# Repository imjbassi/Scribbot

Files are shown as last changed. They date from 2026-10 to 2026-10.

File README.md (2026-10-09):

# Scribbot

A low-cost, mostly 3D-printed desktop robot arm that draws on a 3 × 3 inch sticky note.

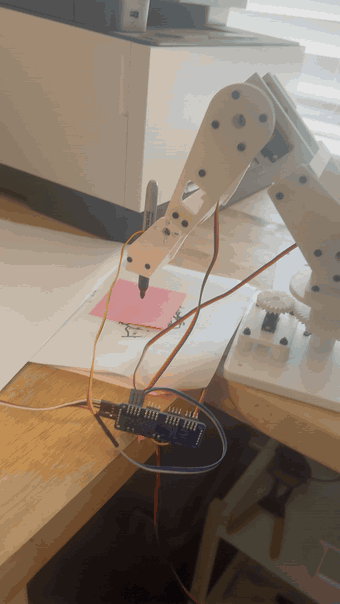
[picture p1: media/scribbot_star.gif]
Scribbot drawing a star on a sticky note


- **4 hobby servos:** MG90S base (through a 2:1 printed gear), MG996R shoulder, MG996R elbow, MG90S wrist
- **Electronics:** Arduino Nano + PCA9685 servo driver, 5 V supply
- **Pen:** a standard Sharpie in a gravity holder. It slides up a few millimeters when it touches the paper, so it presses with just its own weight.
- **Everything printable** is in OpenSCAD source plus ready-to-print STLs (PLA, 0.4 mm nozzle, 0.12 mm layers, no supports)
- **Planned:** a webcam stand and vision, so it can find the paper and draw what it sees

## Build stages

Each folder in [`design/`](design) has a `START_HERE.md` with print settings, hardware and step-by-step assembly, plus diagrams.

| # | Stage | Folder | Status |
|---:|---|---|---|
| 1 | Fit coupons: servo bodies, bearing pocket, slider clearance | [`phase-2`](design/phase-2) | Done |
| 2 | Servo mounting-hole templates | [`mounting-templates`](design/mounting-templates) | Done |
| 3 | Servo mount plates + bearing carrier | [`mechanical-fit-v1`](design/mechanical-fit-v1) | Done |
| 4 | Bearing turntable | [`compact-base-stage-1`](design/compact-base-stage-1) | Done |
| 5 | Base servo mount and gear mesh | [`compact-base-stage-2`](design/compact-base-stage-2), [`base-horn-fit`](design/base-horn-fit) | Done |
| 6 | First power-on: wiring + centering | [`base-servo-test`](design/base-servo-test) | Done |
| 7 | Base calibration + repeatability | [`base-calibration`](design/base-calibration) | Done |
| 8 | Shoulder + load test | [`shoulder-horn-fit`](design/shoulder-horn-fit), [`shoulder-stage`](design/shoulder-stage) | Done |
| 9 | Elbow | [`elbow-stage`](design/elbow-stage) | Done |
| 10 | Wrist + pen holder | [`pen-fit`](design/pen-fit), [`wrist-stage`](design/wrist-stage) | Done |
| 11 | Calibration and drawing software | [`calibration`](design/calibration), [`drawing`](design/drawing) | Done: draws squares, circles, stars and text |
| 12 | Camera stand + vision | | Planned |

[`rotating-base-v1`](design/rotating-base-v1) and [`compact-base-review`](design/compact-base-review) are earlier base designs kept for reference. Don't build them.

The running build log is [`design/CURRENT_BUILD_STATUS.md`](design/CURRENT_BUILD_STATUS.md).

## Geometry

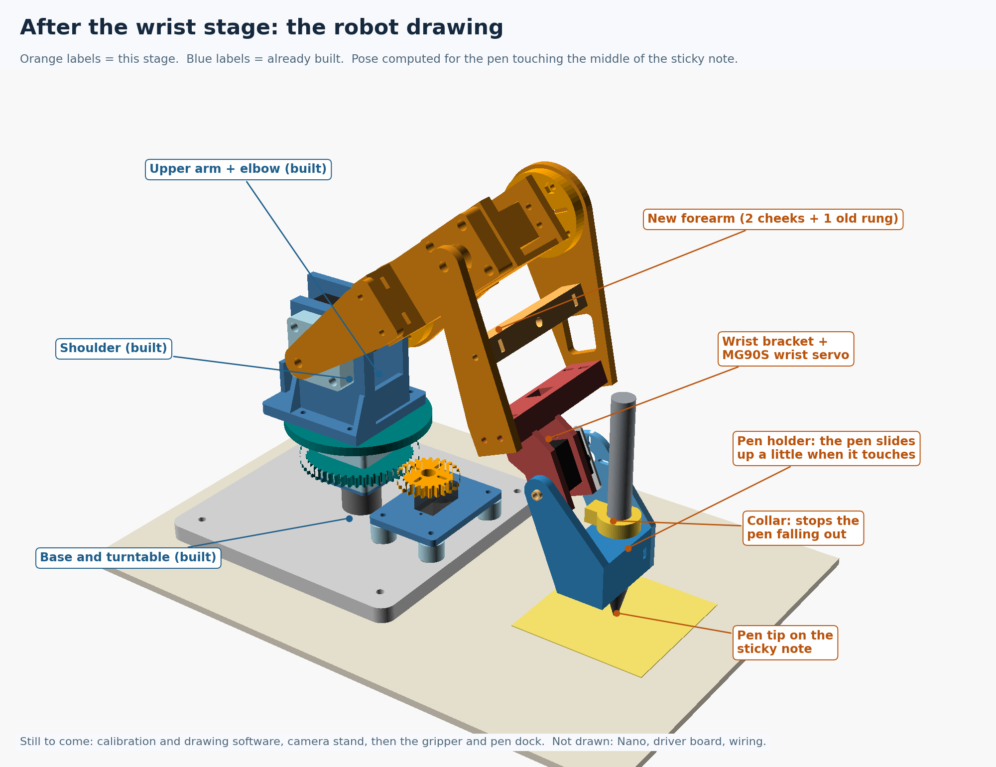
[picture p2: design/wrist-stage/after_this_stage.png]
Scribbot CAD model with its pen on the sticky note


| | |
|---|---|
| Upper arm, forearm | 120 mm each, joint to joint |
| Shoulder axis | 127 mm above the table (measured) |
| Pen | tip 67 mm below the wrist axis (measured), offset 25 mm forward |
| Drawing area | 60 × 60 mm patch on the sticky note, 135-197 mm out from the base |

## Wiring

| Nano | PCA9685 |
|---|---|
| 5V | VCC |
| GND | GND |
| A4 | SDA |
| A5 | SCL |

Servo power goes only into the PCA9685's green screw terminal, never through the Nano. Channels: 0 base, 1 shoulder, 2 elbow, 3 wrist.

## Test program

[`design/wrist-stage/arm_test/arm_test.ino`](design/wrist-stage/arm_test/arm_test.ino) drives all four joints over USB serial (115200 baud, no libraries needed). Commands start with the joint letter: `b` base, `s` shoulder, `e` elbow, `w` wrist. For example `s1300`, `e+`, `wo` (wrist off), or `o` for everything off. Outputs stay off at startup, and every move is slow and stepped.

## Calibration

The servo horns never land exactly on the design angles, so each joint gets an offset and a gain. They come from tape-measure heights of the shoulder, elbow, wrist and pen tip in three poses. In the last pose the wrist works as a level: the pen is set straight down and only the wrist pulse is read. The method and the numbers are in [`design/calibration/measurements.md`](design/calibration/measurements.md).

## Drawing

[`design/drawing/draw/draw.ino`](design/drawing/draw/draw.ino) does the inverse kinematics on the Nano and keeps the pen vertical. Lines are cut into 1 mm steps.

1. Put a sticky note with its center 166 mm (6 1/2 in) straight out from the turntable.
2. `h` hovers over the note. Lower the pen with `d` (1 mm) or `D` (5 mm) until it just touches the paper, then send `t` to save that height.
3. Draw:
   - `q` square
   - `c` circle
   - `s` star
   - `wHELLO` text: letters and numbers, up to 8 characters

`l` / `r` rotate the drawing 1°. `m` / `v` mirror or flip the text. `o` turns every joint off.

## License

[MIT](LICENSE): designs, STLs and code are free to use, modify and share, with the copyright notice kept.

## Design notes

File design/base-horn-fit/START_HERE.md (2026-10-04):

# One small gear: unpowered horn fit check

Print ONLY 01_motor_gear_fit.stl. This is the candidate base-drive pinion, not a release of the complete base. Your double-ended white horn is accepted as fitting your black MG90S shaft, based on your confirmation.

## Print

Use the Bambu A1 mini and the same PLA/profile used for the successful fit coupons: 0.4 mm nozzle, 0.12 mm layers, 0.2 mm first layer. Print flat, at 100% scale, with 4 walls, 5 top/bottom layers and 40% infill. No supports. Remove any brim from teeth and slots. This fit result will apply to this FDM process; resin needs its own fit validation.

## Check without screws or power

1. Leave the servo unplugged. Begin with the horn loose, off the servo.
2. Put the horn against the underside of the gear, with the socket that fits the servo pointing away from the gear. Center the horn's center hole in the gear's large center opening.
3. Align the horn arms with one pair of opposite radial slots. Look through the slots: at least one horn hole on EACH arm must be fully visible. Choose approximately equal distances from the center. You do not need to measure or mark anything.
4. Check whether the gear rests flat and centered against the horn arms. If the hub prevents it sitting flat, stop and report that; do not sand or force the horn.
5. Seat the horn back on the disconnected servo, gently, and hold the gear in place. Check whether the original center screw is accessible through the large gear opening and whether the gear clears the servo case. Do not turn the gear to force the servo shaft.

Reply: "holes line up, sits flat, clears case" or identify which check fails. A photo is useful if something does not line up.

Do not power this loose assembly. No attachment screws are selected yet: the slots are nominally 2.2 mm wide, but this does NOT prove the horn holes accept M2 screws. Screw diameter/length and underside clearance must be matched before fastening. Do not enlarge the horn holes or use glue.

## Design provenance

25 teeth, module 1.25, 6 mm thick; approximate envelope 33.7 x 33.7 x 6 mm. Central access opening 8 mm. Opposite attachment slot center positions span radii 7–11 mm. Geometry copied unchanged from compact-base-review. The photograph identifies the horn shape; no precise horn dimensions were inferred from perspective.

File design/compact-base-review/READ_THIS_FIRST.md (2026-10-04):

# Compact base revision — design review, NOT a print release

The earlier tall rotating-base-v1 package is superseded. Do not buy its 100 mm shaft, collars or M4 x 110 frame bolts for this revision. Keep the successful fit-test parts and bearings. This package is source CAD, reference renders and numerical design checks; it deliberately contains no printable STL release while the actual servo-horn interface remains unresolved.

## Settled layout for this revision

- Fixed 150 x 150 x 9 mm board-mounted base.
- One stationary M5 axle bolt, with two 625 bearings running on its smooth shank.
- Bearing INNER rings stay stationary; OUTER rings turn with the printed rotor, gear and top platform. This reverses the bearing arrangement of the withdrawn design.
- Bearing center spacing: 25 mm. Platform top: 67.4 mm above board.
- Target shoulder-axis height: approximately 115 mm, to be set by shoulder-carrier CAD. A central clearance well must accommodate the stationary bolt/nut stack up to approximately 86 mm above the board; no shoulder part may sweep through it.
- One MG90S beside the rotor, mounted in the previously accepted plate geometry.
- Printed 25-tooth motor gear drives a printed 50-tooth base gear, module 1.25 and 20-degree pressure angle. Nominal shaft spacing is 46.875 mm.
- The drive provides 2:1 torque multiplication before friction; 140 degrees of usable servo travel gives 70 degrees of base travel. Planned base range is -35 to +35 degrees, contingent on actual calibrated servo travel.
- Standard shoulder/elbow servos remain MG996R; optional wrist rotation remains in the mass budget. This base change does not resolve the outstanding shoulder thermal/load test.

## Complete load path

Arm/shoulder carrier -> rotating top platform -> bolted rotor and gear stack -> bearing outer rings -> balls -> stationary inner rings -> narrow washers and central support/spacer stack -> base board.

The MG90S drives through its supplied horn and the small gear. It supports the small gear and receives tooth reaction forces, but not the arm's weight. The pinion is not separately bearing-supported; the hobby servo output still sees gear-mesh radial force. This tradeoff must be checked at low acceleration, rather than claiming the servo shaft is entirely load-free.

## Motor connection: designed concept, one remaining physical check

The small gear bolts to the SUPPLIED horn; no printed spline is used. Candidate gear attachment slots accept M2-sized fasteners at radii 7–11 mm in four directions. The central 8 mm access hole allows the original horn screw to be reached. At least two compatible horn attachment locations are required, preferably on opposite arms. Fasteners must clear the servo case below and the large gear beside it.

The reference render assumes a double-ended 26 mm long, 2 mm thick horn, with attachment locations at +/-9 mm. These are placeholders, NOT measurements of the user's hardware. The photographed MG996R horn assortment does not establish the MG90S horn dimensions.

Update: IMG_9221.png shows a double-ended white horn with multiple holes per arm. The user confirmed this horn seats snugly on the black MG90S shaft without forcing. Shaft compatibility is accepted from that physical check. Exact hole diameters, horn thickness and fastener clearance remain unmeasured. The candidate motor gear is now released separately in ../base-horn-fit for an UNPOWERED alignment check only. Its slots must align with two opposite horn holes while centered. Do not force or drill the horn to match.

Gear-height alignment is adjustable by changing the four printed motor-post heights and using thin shims. The nominal 10 mm posts and 6.5 mm body-to-shaft offset in CAD are layout references. The base slots permit translation to align the gear axes and set mesh clearance. The motor gear and base gear must overlap axially without rubbing, and the original horn screw must be accessible before any powered test.

## Why this is preferable to the withdrawn base

It removes the separate precision shaft, two collars, tall two-deck frame and long M4 bolts. It places the arm much closer to the original height budget and makes the motor accessible from the side. The reduction improves base torque and halves the base angle change corresponding to a given servo angle change.

The tradeoff is printed gear backlash and limited yaw. Nominal tooth thinning produces 0.12 mm total pitch-circle backlash, equivalent to approximately 0.22 degrees at the base, or 0.77 mm at 200 mm radius. Real printed clearances, servo backlash, flex and wear can add more. This is a design calculation, not a measured accuracy specification. Avoid heavy grease on PLA; lubrication selection is not part of this release.

## Reach checks completed

With 120 mm links and an ideal vertical 95 mm tool offset, the checker sampled the 60 x 60 mm drawing patch (X=135..195, Y=-30..30 mm) at tip heights 2, 12 and 25 mm. It also checked provisional dock tip targets at X=145, Y=-75 mm, Z=10/25/40 mm. This replaces the old provisional dock location.

At each of six assumed shoulder heights from 100 to 125 mm, all 510 sampled targets had an IK solution within the chosen candidate joint limits. The dock yaw is approximately -27.35 degrees, within the planned +/-35-degree base sector. At the target 115 mm shoulder height, sampled joint ranges were approximately:

| Joint | Geometric angle range |
|---|---|
| Base yaw | -27.35 to +12.53 degrees |
| Shoulder | 29.15 to 57.87 degrees |
| Elbow | -111.49 to -68.73 degrees |
| Wrist pitch | -56.77 to -26.98 degrees |

These are geometric angles, not raw servo commands. Zero offsets and direction signs remain to be calibrated. The check does not prove full continuous-path coverage, physical servo travel, gripper/dock access, full-pen clearance, or self-collision avoidance. Complete shoulder, wrist and dock meshes are still needed for those checks. Do not use these numbers directly as servo targets.

The 2D involute gear profiles were checked in 561 sampled poses across the planned base range with zero polygon overlap at nominal spacing. Calculated nominal contact ratio is about 1.68. This is a tooth-profile interference check, not a torque, wear or printed-mesh test.

## Prospective parts list — do not purchase yet

### Already available or previously fitted

- 1 MG90S for base drive, with original horn and horn-center screw.
- 2 of the purchased 625-2RS bearings.
- Accepted MG90S plate geometry, rotated 90 degrees for this layout; the existing plate can be reused.
- One tested bearing cap can be reused; two caps total are needed. The old single-bearing carrier is a useful fit reference but does not become the new rotating rotor block.

### Proposed new hardware

| Part | Qty | Required check |
|---|---:|---|
| M5 x 80 partially threaded socket-head bolt | 1 | Smooth shank must cover both bearing journals; minimum approximately 55 mm from underside of head. Threads must reach upper nuts. Bearing fit must not visibly rock. |
| M5 hex nuts, approximately 4 mm thick | 2 | Lock together without overcompressing printed spacers or preloading bearings |
| Narrow M5 washers, 5.3 ID x 9 OD x 1 mm thick | 5 | Must contact inner races only; actual thickness affects axial stack |
| M3 x 45 machine screws | 4 | Through rotating platform + caps + rotor/gear stack |
| M3 nuts | 8 | Four rotor bolts and four motor-plate bolts |
| Thin M3 washers | 16 | Eight for rotor stack, eight for motor plate |
| M3 x 30 socket-head screws | 4 | Motor plate/post/base mounting; exact length after horn-height adjustment |
| M2 x 10 machine screws, M2 nuts, thin M2 washers | 2, 2, 4 | Existing proposed servo-tab fastening; use only if actual tabs accept it |
| Horn-to-gear fasteners | At least 2 | Diameter and length pending actual horn; not yet orderable |
| Approximately 4 x 16 wood screws and washers | 4 | Base to an 18 mm board; check actual engagement |

An undersized general-purpose bolt shank can introduce tilt even when its nominal diameter is M5. Do not assume the bolt is a precision shaft. Verify its two bearing fits before committing to loaded operation. If there is visible rocking or thread contact, this axle choice must be revised. The inner-ring spacers are printed to maximize printable content; compression/creep under clamping is another physical validation item. Jam nuts prevent loosening but do not justify overtightening.

### Proposed print list

Base x1; stationary pedestal x1; lower rotor block x1; upper rotor block x1; large gear x1; small gear x1; rotating platform x1; bearing caps x2 total; inner-ring spacer x1; top spacer x1; motor plate x1 total; motor posts x4. Gear and rotor blocks are separate so the gears can print flat without large unsupported overhangs and can be replaced individually.

## Assembly sequence after interface release

1. Check the actual bolt's smooth journal fit in both bearings and its thread reach. Fit the stationary axle through the base from below, with its head recessed.
2. Stack the stationary pedestal and first narrow washer on the axle. Lower bearing bottom is nominally Z=30.2 mm.
3. Build the rotating shell loosely from lower cap, lower rotor block, large gear and upper rotor block around the axle. The two bearings sit at opposite ends of the 16.3 mm bore; their separation is set by the inner-ring spacer stack, not by the servo.
4. Between the bearings fit a narrow washer, the 18 mm inner spacer, and a second narrow washer. Fit the upper bearing, then the top cap and platform. Bolt the rotating stack with four M3 x 45 screws and washers/nuts. Ensure the bearing outer rings are captured without seal rubbing.
5. Above the upper inner race, fit a narrow washer, 10 mm top spacer, another washer and the two M5 nuts. Adjust to hold the inner-ring stack while allowing free rotor movement. Nominal total outer-race axial freedom is 0.4 mm; printed and washer tolerances may require spacer adjustment. Do not squeeze away a tight spot by tightening harder.
6. Attach the actual supplied horn to the disconnected MG90S using its original screw. Attach the small gear with the matched fasteners once that interface is released. Install the motor plate, posts and servo; align gear height and mesh without binding.
7. Disconnect/disengage the motor gear for the first free-turn test. Then mesh the gears and check tooth engagement gently within the calibrated range; do not force the servo through a hard stop by turning the platform.
8. Only after mechanical fit, safe pulse calibration and the future joint-limit procedure should unloaded powered tests begin. No firmware is supplied in this review package.

## Superseding physical-fit update

The user confirmed the printed motor gear sits flush, opposite holes align, it clears the MG90S case, and the center screw remains accessible. These checks pass. Horn-to-gear fastening is still unresolved; the user has only supplied servo screws. The next limited release is ../compact-base-stage-1: a passive turntable prototype, motor detached. Its instructions supersede the earlier request to repeat the horn fit check. The full powered base remains unreleased.

## Previous next-action note (superseded)

Use the separate base-horn-fit instructions for the small gear alignment check. Do not print the full base or buy the prospective hardware yet. The existing fitted components remain valid. The next release should contain a matched motor connection, final hardware schedule and one assembly guide, rather than another disconnected test structure.

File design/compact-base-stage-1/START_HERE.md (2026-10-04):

# Use the consolidated build guide

Open [BUILD_GUIDE.html](BUILD_GUIDE.html). It is the current guide and includes the fully threaded axle limitation, hardware inventory, numbered diagram and expanded assembly steps. No STL geometry changed.

The earlier instructions below are retained as a design reference; follow the consolidated guide when they differ.

---

# Next build: passive compact turntable

This is the bearing-supported rotating base, assembled WITHOUT the motor gear engaged. It is an engineering prototype for physical fit and hand-turn testing, not a validated complete robot. The old tall base remains superseded.

## Confirmed and pending

You confirmed the white horn fits the black MG90S, the small gear sits flush, opposite holes align, the gear clears the case, and the center screw is accessible. Keep that printed gear. Those checks do not establish attachment screw size or loaded performance. You have only the supplied servo screws. Do not force them into the horn or substitute a long screw for the original center screw. Horn-to-gear fastening remains pending; the motor stays detached in this stage.

## Print list

Print flat as exported, 100% scale, PLA, 0.4 mm nozzle, your tested 0.12 mm layer / 0.2 mm first-layer profile. Use 4 walls, 5 top/bottom layers and 40% infill; use 100% infill for the pedestal and both inner-ring spacers. No supports. Inspect bridges over underside base recesses; remove loose strands before fitting hardware. Do not transfer the validated FDM clearances directly to resin.

| File | Total quantity | Notes |
|---|---:|---|
| 01_base.stl | 1 | 150 x 150 mm; new compact base |
| 02_fixed_pedestal.stl | 1 | Narrow end points upward |
| 03_lower_rotor.stl | 1 | 9 mm tall |
| 04_large_gear.stl | 1 | 50 teeth |
| 05_upper_rotor.stl | 1 | 15.4 mm tall |
| 06_bearing_cap.stl | 2 total | Reuse your accepted plain cap; print only one more if you have one |
| 07_top_platform.stl | 1 | 80 mm diameter |
| 08_inner_spacer_18mm.stl | 1 | Between inner bearing races |
| 09_top_spacer_10mm.stl | 1 | Above upper inner race |

Ten pieces total, or nine new pieces if reusing one cap. Reuse the small gear and MG90S mounting plate later. The old single-bearing carrier is NOT one of the new rotor blocks. Print one file at a time or arrange separate plates; do not stack the STLs on the slicer bed.

## Hardware required for this stage

This is a dimensional specification, not a verified supplier listing. Check any hardware you already own before ordering.

- Two 625-2RS bearings, 5 x 16 x 5 mm, from your existing supply.
- One M5 x 80 partially threaded socket-head bolt. Its smooth shank must extend at least 55 mm from under the head, with usable threads at 66.7–74.7 mm from under the head. A fully threaded bolt is unsuitable. Head must fit a 9.6 mm diameter x 5.5 mm-deep recess. Both bearings must slide onto the smooth shank without visible rocking; a nominal M5 label alone does not prove the fit.
- Two ordinary M5 hex nuts, approximately 4 mm thick each, used as jam nuts.
- Five narrow washers: approximately 5.3 mm ID, 9 mm OD, 1 mm thick. They must bear on the bearing INNER metal ring without touching the rubber seal. Check the actual bearing contact; dimensions alone do not guarantee seal clearance.
- Four M3 x 45 machine screws, four M3 nuts and eight thin M3 washers (approximately 0.5 mm thick). These clamp the rotating shell, not the fixed axle.

Do not buy the withdrawn design's 100 mm shaft, collars or long frame bolts. No motor fasteners or board screws are required for the initial bench fit. The base must later be secured before powered or loaded use.

## Assembly: two stacks share one axle

Use numbered_connection_guide.png alongside this sequence; its part numbers match the STL filenames. The inner stack stays still. The outer shell rotates around it. All heights are nominal; washer and print thickness affect the fit.

1. With the axle loose, check both bearings on its SMOOTH shank. Stop if the fit rocks visibly, binds, or puts a bearing on threads.
2. Insert the M5 bolt upward through the base from underneath. Seat its head in the recess. Place the pedestal over the axle, narrow tip upward, then one narrow washer.
3. Lower a bearing cap and the lower rotor over the pedestal tip. Insert the lower bearing into the rotor from above, sliding its inner ring onto the axle until it rests on the narrow washer. The bearing must be supported through its inner ring; do not press through its seal.
4. Add a narrow washer, the 18 mm spacer and another narrow washer onto the axle. Add the large gear and upper rotor around that stack. Align all four corner holes through the rotating parts.
5. Slide the upper bearing into the upper rotor from above until its inner ring reaches the washer. Add the second bearing cap and top platform. Insert four M3 x 45 screws through the corner-hole stack with washers and nuts. Tighten evenly only until seated; stop if tightening introduces binding or distorts the prints.
6. Above the upper bearing INNER ring, add a narrow washer, the 10 mm spacer and the fifth narrow washer. These pass through the cap/platform center opening. Add the two M5 nuts. The lower nut holds the stationary inner stack; the upper nut locks against it. Hold the lower nut while tightening the upper so you do not change the stack compression.
7. The design leaves approximately 0.4 mm total outer-ring axial clearance. Check for rubbing and excessive play. Do not eliminate binding by overtightening. If the washer stack differs or the assembly binds, report it so spacer length can be adjusted.

## Pass/fail before adding the motor

With the motor gear detached and no arm attached, hold the base and turn the platform by hand through one full turn. Bearing seals may add gentle, consistent drag.

PASS: smooth movement without a tight spot, no seal/cap scraping, no visible rocking of the platform, axle remains fixed, and the printed stack stays clamped. Repeat after locking the M5 nuts.

FAIL: catching, grinding, obvious wobble, bearing threads contact, or movement becomes tight after locking nuts. Stop and identify which symptom occurs. Do not add the motor or power it to overcome resistance.

Report: "turntable turns smoothly, no wobble" or the symptom. This test establishes unloaded fit only; loaded deflection, backlash, thermal behavior, fasteners and powered travel remain later checks.

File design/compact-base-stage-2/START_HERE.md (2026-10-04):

# Stage 2: fit the MG90S beside the turntable

## Current status

You assembled the turntable with a fully threaded M5 axle and reported smooth turning and secured side bolts. Earlier wobble was reported; its cause and loaded behavior are not established. At your request, axle replacement is deferred for an UNLOADED prototype. Keep the arm off; inspect for renewed rocking, binding or wear before moving on to loaded work. This supersedes the earlier instruction to stop all fitting work pending axle replacement.

This stage positions the servo and checks gear height. It does not release powered operation. The horn-to-gear screws remain unspecified.

## Print only these two files

- posts_set_of_4.stl: print ONE copy of this file. It already contains all four 10 mm motor posts.
- shoes_set_of_4.stl: print ONE copy of this file. It already contains all four thin backing plates.

Use your tested PLA process, 0.4 mm nozzle, 0.12 mm layers, 0.2 mm first layer, 100% scale, 4 walls and 100% infill; flat as exported, no supports. Do not print four copies of either file. The post height is provisional until the real installed horn height is checked.

Reuse your accepted MG90S mounting plate and small gear. Do not reprint the turntable. The existing plate is 64 x 44 mm; rotate it so its long direction runs front-to-back along the base's motor slots. Its raised label faces up.

## Hardware from your M3 kit

Four M3 x 30 BUTTON-head screws, eight M3 flat washers, four M3 nuts. Do not use M4 screws or split lock washers. The button heads are the low rounded heads in your first kit.

The backing plates bridge the wide slots underneath the base. Each is 10.4 x 18 x 1 mm, with a 3.4 mm hole. They belong inside the elongated underside recess, not on top of the base. Their narrow edge leaves limited adjustment; do not force them beyond the recess. This is a prototype printed support for the small motor mount, not a tested structural washer replacement for other joints.

## Install each of the four mount bolts

See motor_mount_guide.png. Start beneath the base:

M3 screw head -> M3 flat washer -> thin printed backing plate -> slotted base -> 10 mm post -> existing MG90S plate -> M3 flat washer -> M3 nut.

1. Lift/support the base to reach its underside; do not dismantle the central turntable.
2. Put a washer on each M3 x 30 button-head screw. Pass it through a backing plate, then UP through a motor slot from below. The backing plate's 18 mm direction follows the long recess.
3. Put one 10 mm post over each screw on TOP of the base.
4. Lower the existing servo plate onto all four posts. Add washers and nuts above it. Leave the nuts loose enough for gentle adjustment.
5. Check underneath. Each backing plate must lie flat in its recess and bridge the slot. Screw heads must not make the base rock on the table. If they protrude or a backing plate bends, stop and report that; do not crush it by tightening.

## Place the servo and check gear height

6. With its horn removed, gently feed the MG90S lead and body through the plate's rectangular opening from ABOVE. Mounting tabs rest on the plate. Do not trap the cable between the plate, posts or base. If the cable plug will not pass, route it before lowering the plate.
7. The servo shaft faces UP. Start with the output shaft approximately aligned with the middle of the large gear in the front-to-back direction; the adjustment slots compensate for the actual servo shaft offset. Keep the small gear out of mesh for now.
8. Servo-tab fastening is not resolved by the M3 kit: the plate has 2.2 mm mounting holes. Do not force M3 screws into them. You may hold the servo seated by hand for this static alignment check. This is not a secure operating mount.
9. Seat the already-tested white horn on the shaft without forcing or twisting it. Hold your small gear on top in its confirmed flush orientation. It is not secured yet; keep a hand on it.
10. Look from the side. The two gears are each 6 mm thick. Their top and bottom faces should be at approximately the same heights, with most of their tooth height overlapping. If the small gear is high or low, do not tilt the servo plate: all four posts must change height equally. The 10 mm posts are a starting point, not a measured final height.
11. Move the plate gently toward the large gear until teeth can enter the gaps. If tooth tips meet, move apart and rotate the LARGE platform slightly, then bring them together. Do not force the small gear or back-drive the servo. The plate should remain level; neither gear nor horn should rub the servo case or platform.
12. Take a SIDE-ON photo showing both gears and the servo plate. Keep the small gear loose and disengage it after the check. Do not rotate the whole assembly as a driven system until the gear is fastened and servo travel is calibrated.

## Report these three things

- Does the servo plate sit level, with the base still flat on the table?
- Is the small gear level with the large gear, higher, or lower?
- Does the cable have clearance without being pinched?

A side-on photo can answer most of this. Include the supplied servo screws beside the assembly if handy; that helps distinguish the original center screw from the mounting screws without assuming their sizes.

## Before powered use (not completed in this stage)

Select and verify servo-tab fasteners and two opposed horn-to-gear fasteners, resolve actual gear height and mesh clearance, secure the base, and calibrate the servo with the gears disengaged. The original center screw attaches the horn to the servo; it does NOT secure the printed gear to the horn. Do not glue the gear or substitute a longer center screw.

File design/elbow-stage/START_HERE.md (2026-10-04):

# Stage 6: elbow joint

The elbow is a copy of the shoulder joint, carried on a short new upper arm. Your 120 mm test arm is not wasted: it moves out to the elbow and becomes the forearm.

Pictures in this folder:

- `after_this_stage.png`: what the robot looks like when this stage is done
- `construction_diagram.png`: exploded view, numbered in build order
- `screw_map.png`: every screw, lettered, with what it passes through

## Print

All PLA, your 0.12 mm profile, 100% scale, flat as exported, no supports.

| File | Qty | Settings |
|---|---:|---|
| 09_elbow_bracket.stl | 1 | 3 walls, 20% infill. Prints standing up, 85 mm tall, thick end plate on the bed. |
| 10_upper_cheek_A_hub_side.stl | 1 | 4 walls, 40% |
| 11_upper_cheek_B_bearing_side.stl | 1 | 4 walls, 40% |
| 01_hub_PRINT_1_MORE.stl | 1 | 4 walls, 40% |
| 03_bearing_housing_PRINT_1_MORE.stl | 1 | 4 walls, 40% |
| 04_bearing_cap_PRINT_1_MORE.stl | 1 | 4 walls |
| 08_axle_spacers_PRINT_1_MORE.stl | 1 | 100% infill |

## Hardware (new for this stage)

- The second MG996R, its double-arm horn, 2 horn screws and its center screw
- 1 × 625 bearing
- 1 × M5 bolt, washer and nut, the same kind you used at the shoulder
- M3 × 16: 8, M3 × 20: 4, M3 × 12: 4, M3 nuts: 12, M3 washers: 8

## Wiring and program

- Elbow servo plugs into **channel 2** on the driver board (next to the shoulder on channel 1), brown wire toward the board edge.
- Upload `arm_test/arm_test.ino`. It drives all three joints. Every command starts with the joint letter: `b` base, `s` shoulder, `e` elbow. Examples: `e1500`, `s+`, `eo` (elbow off), `o` (everything off).

## Build order (numbers match construction_diagram.png)

**Take the test arm off the shoulder first**
1. Type `o` and unplug the adapter. Support the arm.
2. Undo the M5 nut and washer on the bearing side. Take out the 3 rung screws on cheek B and pull cheek B off. Leave the spacers on the bolt.
3. Undo the 4 screws holding cheek A to the shoulder hub. The test arm (cheek A with its 3 rungs) comes off as one piece. Leave the hub on the servo.

**Upper arm onto the shoulder**
4. Upper cheek A onto the shoulder hub with the same 4 screws, pointing **straight forward**, where the test arm pointed.
5. Drop 4 M3 nuts into the slots at the two ends of the bracket's thick end plate. Hold the bracket between the cheeks with its two walls pointing away from the shoulder. The **thin wall with the window goes on the hub side**. Two M3 × 16 through cheek A into the bracket.
6. Upper cheek B over the shoulder bolt, two M3 × 16 into the bracket, then the M5 washer and nut back on.

**Elbow joint (same as the shoulder)**
7. M5 bolt through the bearing and new housing, cap on, 4 × M3 × 20 into the bracket's back wall. Bolt head inside the big hole. Leave the screws slightly loose.
8. Plug the second servo into channel 2. Power on, type `e1500`, then `eo`, and unplug. The servo is now centered.
9. Slide the servo into the bracket's window from the hub side. Its shaft must line up with the big hole in the back wall, so the **shaft end points away from the shoulder**. Bolt the tabs with 4 × M3 × 16, washers and nuts.
10. Press 4 M3 nuts into the new hub's hex pockets. Screw the horn to the hub with 2 horn screws. Press it onto the shaft and put the center screw in.
11. Test arm onto the new hub with 4 × M3 × 12, pointing **straight down** when the upper arm is level (a right angle to the upper arm, as close as the horn's teeth allow). Raise the upper arm by hand first so the forearm has room.
12. Spacers on the elbow bolt, cheek B over the bolt, its 3 rung screws back in, then the M5 washer and nut.
13. Swing the forearm gently by hand to line up the bearing, then tighten the 4 housing screws.

## First power-on

Keep the base clamped. Hold the forearm lightly in your hand.

1. Type `s1500`. The upper arm goes level.
2. Raise the upper arm: on the shoulder, **lower numbers go up**. Type `s1400`, `s1300`, `s1200`, `s1100`, `s1000`, pausing at each, until it is about halfway to vertical. This gives the forearm room. The program stops the shoulder at 1550, just below level.
3. Type `e1500`. The forearm should hang at a right angle to the upper arm.
4. Type `e1400`, then `e1600`, then `e1500`. It should swing smoothly both ways.

**Stop** (type `o` with the arm supported) if anything binds, buzzes loudly or heads for the table.

## Report back

- Which elbow number swings the forearm **forward and up** (away from the base): `e1400` or `e1600`?
- Does it all move smoothly? A photo of the arm helps.

## Known limits

- The test arm is heavier than the final forearm will be. It is fine for this stage; a lighter forearm comes with the wrist.
- With the upper arm level and the elbow at a right angle, the forearm reaches the table. Raise the shoulder before bending the elbow down.
- Collision checks in CAD: forearm against upper arm clear from 20° past straight to folded 140°; arm against the shoulder mount clear from level to 120° up. The base, table and cables are not in that check.

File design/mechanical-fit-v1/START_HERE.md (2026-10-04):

# First mechanical interfaces — fit release V1

This release converts the accepted mounting templates into removable screw-mounted servo plates and a common base interface. It also tests a captured 625 bearing. It is NOT the complete robot, a finished shoulder/elbow joint, or a load-test fixture. No servo should be powered in this assembly yet.

Editable OpenSCAD source: set `part` to `assembly_micro`, `assembly_standard`, or `exploded_standard` to inspect the pedestal arrangement. Gray servo boxes are approximate envelope references only, and omit ears, horns, screws and wires. Never export these assembly previews as printable parts. Export the individually named part options instead. STEP files are not included in this OpenSCAD fit release.

## Print first

Print one each of `01_mg90s_mount_plate.stl`, `02_mg996r_mount_plate.stl`, `03_625_bearing_carrier.stl`, and `04_625_bearing_cap.stl`. Each has one part. Print flat, labeled face up where present, at 100% scale with your confirmed PLA/0.4 mm nozzle/0.12 mm layer profile and 0.20 mm first layer. Use four walls and at least five top/bottom layers; no supports. Print carrier pocket upward. Clear loose strings without enlarging fit surfaces.

Do not print extra shoulder/elbow copies yet. These plates establish interfaces for those later modules; their carrier structures and horn couplings are still pending.

## What to test

### Servo plates

Feed the cable through the body opening, then insert the servo from the labeled side. Tabs rest on the 4 mm thick plate. Check that every intended screw location aligns while the body sits naturally. There must be no need to bend tabs or squeeze the body. Reference openings are 23.4 x 12.8 mm for MG90S and 41.3 x 20.3 mm for MG996R.

MG90S uses the selected 27 mm spacing and 2.2 mm holes intended for M2 machine screws. MG996R uses 49 x 10 mm spacing and 3.4 mm holes intended for M3 machine screws. Actual servo slot width and supplied screws have not been verified. Try any available correctly sized screw gently; do not drill the servo or force an oversized screw. A smaller screw with appropriate washers can be evaluated if the slot will not accept the proposed size. The supplied coarse servo mounting screws are not assumed to match these machine-screw holes.

The four outer M3 holes on either plate have identical 52 x 32 mm center spacing. They attach the plate to a pedestal independently of the servo tab screws. Use washers on servo tabs where they fit without touching the body; tighten only enough to retain the servo without deforming its plastic tabs. Report interference instead of forcing it.

### Bearing carrier and cap

Insert ONE 625-2RS bearing into the 16.3 mm pocket from above. It should seat on the narrow outer support rim; nominal bearing top is 0.2 mm below the housing top. Set the cap over it, aligning four holes. The 14.6 mm central openings retain the bearing near its outer edge while leaving the shaft and inner race clear. Confirm the printed rims do not rub either rubber seal: actual bearing ring geometry varies.

With the cap held in place by fingers, turn the inner ring gently. Compare freedom of rotation with the loose bearing. If it binds or the seal rubs, stop and report it. Then, if hardware is available, fit four M3 x 16 machine screws, eight thin M3 washers and four M3 nuts. Tighten evenly and lightly. Check again. The bearing must not escape and should have only small axial clearance, not intentional preload. No axle or servo load is applied in this test.

The later major joints use TWO bearings each; this test only validates one retained bearing interface. It does not prove bending capacity, shaft alignment or a complete load path. Smooth metal journals and inner-race spacers will be specified with the complete joint; do not use bolt threads as final bearing journals.

## Optional base assembly after plate fit succeeds

`05_base_plate.stl` is 150 x 150 x 7 mm plus its label and fits the A1 mini bed. Print label upward; the small 7 mm underside counterbores require short bridging, not supports. `06_mg90s_spacers_4x.stl` contains four 20 mm high spacers; `07_mg996r_spacers_4x.stl` contains four 35 mm high spacers. Use only the matching spacer set for whichever servo plate is installed. They provide an open-sided, removable pedestal, not a closed housing. Verify clearance under actual servo cases, case screws, connectors and wire bends before tightening.

Stack, from bottom up: M3 screw head + washer, base plate, spacer, servo plate, washer + nut. Four M3 x 35 screws suit the nominal micro stack, or four M3 x 50 suit the standard stack. Check protrusion with actual nuts/washers. Under-base nuts for the servo tab screws remain separately accessible. The base access window and open sides allow cable routing and access.

Both servo plates fit the same outer bolt pattern; this makes the mounting platform swappable. Their OUTPUT SHAFT positions are not guaranteed to coincide. A later bearing support and horn coupling must align to each actual servo shaft; this release does not claim a drop-in drive-axis upgrade.

Board holes are 4.5 mm diameter on 124 x 124 mm centers. Four approximately 4 x 16 mm wood screws and washers suit an 18 mm board with this 7 mm base, subject to actual screw/washer thickness. Four underside pockets, 7 mm diameter and 3.6 mm deep, recess the module's M3 socket heads and thin washers. Check that these sit flush or below the bottom surface before anchoring the base. Use washers that fit the recess; report any protrusion rather than bending the base flat. Remove the base from the board to access the recessed heads when changing the module.

## Hardware for one initial fit of each plate and one bearing pod

No purchases are needed just to check that the servo bodies and bearing seat correctly. For screw-fastened checks, the following is a provisional allocation, dependent on actual servo slots accepting the screw diameters:

| Item | Quantity | Purpose |
|---|---:|---|
| M2 x 10 machine screw | 2 | MG90S tab attachment |
| M2 nut | 2 | MG90S tab attachment |
| M2 thin washer | 4 | MG90S attachment, clearance permitting |
| M3 x 12 machine screw | 4 | MG996R tab attachment |
| M3 x 16 machine screw | 4 | Bearing cap |
| M3 nut | 8 | Standard servo and bearing cap |
| M3 thin washer | 16 | Standard servo and bearing cap |
| Owned 625-2RS bearing | 1 | Retention test |

Optional base pedestal: four M3 x 35 OR four M3 x 50 screws, four M3 nuts and eight thin washers. The micro mounting interface introduces M2 hardware because these tabs should not be assumed to accept M3. Final arm quantities remain pending assembly CAD.

## Report back

1. MG90S: sits flat, both holes align, screw size tried (if any).
2. MG996R: sits flat, all four holes align, screw size tried (if any).
3. Bearing: seats fully, cap sits flat, inner ring still turns freely.
4. Any rubbing, interference or loose fit; a photo is useful if unclear.

Remaining mechanical work: output-horn attachment, shaft-axis position, bearing-support carriers, link geometry, complete assembly clearances, gravity/load verification and wrist module packaging. Earlier inferred tab heights are provisional; this release uses open space and through-fasteners to avoid tightly fitting unverified tab thicknesses.

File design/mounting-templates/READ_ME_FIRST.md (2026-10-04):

# Servo mounting-pattern fit templates

Print one copy of each STL. These are thin fit gauges, not operational brackets.

## Settings

Use your tested A1 mini setup: 0.4 mm nozzle, Generic PLA profile, 0.12 mm layers and 0.20 mm first layer. Print flat, labels up, 100% scale, no supports or raft. All islands must remain at their original scale if rearranged. MG90S layout is 82 x 83 mm; MG996R layout is 128 x 168 mm, within a 180 mm square bed. If a brim exceeds the slicer's allowed area, omit it or rearrange the individual pieces. Do not print both complete layouts together unless rearranged to fit.

Each STL contains multiple separate labeled plates: five MG90S options and nine MG996R options. Keep labels readable; remove loose strings without enlarging the holes.

## How to test

1. Keep the servo unplugged and remove any output horn that obstructs handling. Do not remove its case screws.
2. Feed the cable connector through the large rectangular opening first. Lower the servo body into that opening from the labeled side, so its mounting tabs rest on the plate.
3. Gently center the body in the opening. Its clearance is intentional; do not push it to one end to make only one hole align.
4. Hold the plate and servo together and inspect from UNDERNEATH, using a light. Compare each small printed hole with the rounded center of the servo mounting slot above it. Look for symmetric alignment at BOTH ends; on MG996R check all FOUR holes simultaneously.
5. Choose the label whose holes are most centered together. These small holes are visual references, not finished screw clearance holes. No new screws, pins or tools are required. Do not force screws through them.
6. Send the winning label for each servo. If adjacent options look equally good, send both labels and an underside photo of the best seated fit. If none fits, report that instead of forcing it.

The template is symmetric; servo direction does not matter. Raised labels sit outside the nominal servo footprint. If a particular servo's tab reaches a raised label and cannot sit flat, report that interference.

## Options

| Label | MG90S A, mm |
|---|---:|
| M1 | 27.0 |
| M2 | 27.5 |
| M3 | 28.0 |
| M4 | 28.5 |
| M5 | 29.0 |

| Label | MG996R A, mm | MG996R B, mm |
|---|---:|---:|
| S1 | 49 | 9 |
| S2 | 49 | 10 |
| S3 | 49 | 11 |
| S4 | 50 | 9 |
| S5 | 50 | 10 |
| S6 | 50 | 11 |
| S7 | 51 | 9 |
| S8 | 51 | 10 |
| S9 | 51 | 11 |

A is the lengthwise spacing between corresponding hole centers on opposite ends. B is the spacing between the two holes on ONE MG996R mounting tab.

These are candidate dimensions, not measurements inferred as certain from the photos. Existing confirmed body openings are 23.4 x 12.8 mm for MG90S and 41.3 x 20.3 mm for MG996R. This test checks body-to-hole-pattern alignment; it does not establish output shaft position, horn fastening geometry, tab thickness or structural strength. The next bracket fit test will retain adjustability where needed.

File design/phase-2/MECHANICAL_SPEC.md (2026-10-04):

# Vision Draw Arm — phase 2 preliminary design

Status: engineering proposal and printable fit tests; not a validated arm assembly.

## Accepted configuration

Use two positional 180-degree MG996R servos (shoulder and elbow), and four owned MG90S servos (base yaw, wrist pitch, optional removable tool roll, gripper). The roll axis is along the pen axis when drawing. It rotates the gripper and cartridge for dock alignment, and remains fixed during drawing. It must not be implemented as a sideways wrist yaw axis: that would change the constrained inverse kinematics. Leave enough wire loop for limited roll, never continuous rotation.

Links are 120 mm center-to-center. Shoulder height is nominally 100 mm above the board. Target wrist-to-tip distance is 95 mm with the roll module; it must be measured on the assembled tool and entered into calibration. Base plate remains 150 mm square. Maximum straight-link reach is 240 mm, not the recommended drawing radius.

Use a single approximately 76.2 mm square sticky note, not a stack. Initial drawing region is 60 mm square. Measure the actual note before changing holder parameters. Place its center nominally at robot (165,0) mm, edges parallel to robot X/Y, giving drawing bounds X=135..195, Y=-30..30 mm. Maximum radial drawing distance is approximately 197.3 mm. Put the adhesive edge against a registration edge. The holder bed is 2 mm thick; calibrate paper Z on its actual surface. Recess all mounting screws or keep them outside the motion envelope.

Provisional dock location is (130,-90) mm, radius 158.1 mm. This is a layout target only: full pen length, upper barrel sweep, jaw opening and all approach heights must pass collision checks before fixing the dock. Provide slotted dock mounting in later CAD.

## Wrist module load budget

Original endpoint gripper/cartridge/pen budget: 60 g. Add 13.4 g roll servo and 15 g combined roll bracket, bearing/bush and coupling allowance: 28.4 g increase. Tool endpoint budget becomes 88.4 g. Keep total wrist-to-tip length at or below 95 mm if feasible. Weigh the completed tool; an overweight tool triggers recalculation.

Horizontal gravity estimate, mass in kg and radius in cm:

Shoulder = 0.045*6 + 0.075*12 + 0.040*18 + 0.025*24 + 0.0884*24 = 4.6116 kgf cm.

Elbow = 0.040*6 + 0.025*12 + 0.0884*12 = 1.6008 kgf cm.

At 2x allowance these become 9.2232 and 3.2016 kgf cm. The shoulder is almost at the published 9.4 kgf cm stall figure at 4.8 V. This is insufficient evidence of a thermally reliable shoulder. Previous confidence in the five-servo configuration does not carry over unchanged to the roll-equipped version.

Retain the roll module as requested, but require a shoulder load test before full-arm printing. The standard bracket should allow a later servo replacement. If the test fails, first remove roll and retest; then choose between a measured counterbalance solution and a stronger shoulder servo with verified dimensions and ratings. Do not assume a generic “20 kg” label solves backlash or thermal duty. Do not increase the supply voltage without verifying every attached servo.

The calculation assumes the distal assembly is centered below the wrist when drawing. During handling its horizontal center-of-mass offset can increase shoulder torque by up to approximately 0.0884*9.5=0.84 kgf cm in an unfavorable orientation. Such poses are excluded from the initial loaded motion plan. Pen drag and acceleration add load; the 2x number is an engineering allowance, not a continuous torque rating.

## Mechanical interfaces to implement after measurement

- Base, shoulder and elbow use six total 625-2RS bearings (5x16x5 mm). Smooth metal journals carry bearing inner races; clamped printed carriers carry outer races. Hardware geometry must be resolved in assembly before ordering final pivot bolt lengths.
- Use supplied servo horns, never printed splines. The horn transmits torque; separately supported pivots carry structural loads. Provide accessible center screws and removable couplings.
- Link ends use removable end fittings and M3 captive-nut interfaces. Nominal tool-module interface: four M3 clearance holes on a 24 mm square, centered on the tool axis. This is a reserved envelope, not a released fabrication drawing.
- Tool roll uses a coaxial removable cartridge and limited angular travel. Keep the complete pen, including barrel above the grip, inside collision models. A servo/body interference check is required before releasing wrist CAD.
- The compliant pen cartridge has 6 mm stroke, keyed slider, positive retaining flange and adjustable spring seat. Spring force target is approximately 0.1–0.4 N, plus moving weight and friction. Calibrate force with a scale before drawing.
- Use a gripper with synchronized opposing racks. Grip the cartridge neck below its flange. The dock supports the cartridge without loading the pen tip and leaves both jaws clear.

## Exact measurements needed

Measure one representative MG90S, then check the others for differences. Repeat for the actual purchased shoulder/elbow servos. Record in MEASUREMENTS.csv, in millimeters. A digital caliper is helpful.

1. Body length and width below the mounting ears, excluding wires.
2. Body depth below mounting ears and total height to top of output shaft.
3. Overall mounting-ear span and ear thickness.
4. Mounting-hole center spacing in both directions and hole diameter.
5. Output-axis location from two perpendicular body faces.
6. Supplied horn diameter/length, thickness, fastening-hole pattern and installed offset from the body.
7. Center screw specification from supplied hardware; do not guess thread size.
8. Wire exit location and bend-clearance envelope.
9. Actual positional travel after gentle bench calibration; do not command hard stops.
10. Pen diameter, total length, grip-to-tip distance, mass; sticky-note width/thickness; webcam dimensions/mass; resin name/type and its recommended post-cure process.

No exact servo ear spacing or spline geometry has been assumed in the fit coupons. They test BODY clearance only. Do not force a servo through a coupon or use the coupon as a structural bracket.

## First prints and how to judge them

Print MG90S coupon, bearing coupon and slide coupon first in the FDM material intended for final parts. Use 0.2 mm layers and the same wall settings as the later bracket. Each separate coupon island is intentionally disconnected in the STL. Raised labels identify opening allowances. Print flat, without support, and remove elephant-foot edges before evaluating.

MG90S and MG996R coupons provide total added body width/length of 0.4, 0.6 and 0.8 mm (half that clearance per side). Select the smallest opening that accepts the body without force. The MG996R coupon should wait until the actual servos arrive. A body's rounded corners and taper may require additional changes.

Bearing coupons have through-bores of 16.0/16.1/16.2/16.3 mm. Select a sliding/snug hand fit; retention will come from caps, not heavy interference. Slide channels provide 0.2/0.3/0.4 mm lateral clearance per side. Select a channel that moves freely after cleaning, then test again under representative side load. This open channel only measures lateral fit; it is not a finished anti-rotation linear guide.

The note holder is an initial flat backing and registration fixture, sized for a single nominal 76.2 mm note. Its two low edges locate the note, leaving opposite edges accessible. It has four 4.5 mm mounting holes outside the paper. Verify the note stays flat; adhesive variability may require a small removable edge tape outside the drawing patch. This first holder is parameter-adjustable by reprinting, not mechanically adjustable. A later slotted guide version can accommodate multiple sizes without reprinting.

Resin is optional for dimension coupons, gripper pinion/racks, cartridge inserts and fixtures. Use a suitable tough/engineering resin after checking its datasheet; ordinary brittle resin is not the default for structural links, flexures or screw-loaded servo brackets. Evaluate fit after full prescribed post-cure. Resin shrinkage means FDM-selected clearances do not transfer automatically. Use the printer/material manufacturer's handling and processing instructions.

## Bench gates before completing the arm

These are proposed project acceptance criteria, not manufacturer limits or measured performance.

### Shoulder load test

1. Mount the servo and supplied horn on a rigid temporary fixture. Support the test lever so radial load is not carried solely by the servo spline. Provide a catch under the lever and accessible power disconnect.
2. Confirm unloaded movement around the intended working pose, calibrated pulse range and stable supply voltage.
3. For the roll-equipped gravity budget, an approximately 235 g load at 200 mm gives 4.7 kgf cm. Subtract the lever's own moment from the added load. Begin at 25% load, then 50%, 75%, 100%, supporting it while changing weights.
4. At each step hold for 30 seconds, checking for sag, buzzing and supply collapse. At full load extend to 2 minutes, then 10 minutes only if stable. Do not deliberately stall the servo.
5. Conservative project stop: case surface reaches 45 C, rises more than 20 C above ambient, motion becomes unstable, or supply falls below the servo's verified minimum. Use a thermometer; touch is not a measurement.
6. Pass: no stop condition, less than 1 degree additional sag from the settled starting position, and no continued rapid temperature rise at ten minutes. Passing supports a prototype only; repeat with actual duty cycle and complete arm later.

### Base repeatability

1. With links supported and pen lifted, attach a lightweight 200 mm pointer or use the final pen over a reference grid.
2. Command the same central target 20 times from clockwise approach and 20 times from counterclockwise approach at low speed.
3. Measure endpoint position after settling each time. Pass for initial 60 mm symbols: total spread no more than 2 mm and mean approach-direction separation no more than 2 mm. If failed, inspect horn fastening, bearing fit and cable torque; do not claim software interpolation removes backlash.

### Dock pickup

1. First perform ten open-gripper approaches above the dock, then lower incrementally after checking clearances.
2. Grip the cartridge, lift 20 mm, hold five seconds, replace, open and withdraw. Run slowly with an accessible disconnect.
3. Pass: 20 consecutive complete cycles without dropping, binding, scraping the tip, or shifting the cartridge grip height by more than 0.5 mm. Failure requires dock/gripper changes before adding automatic vision.

### Compliance and drawing

1. With the tool held vertical, measure force against a scale at several displacements through the usable stroke. Confirm return without sticking and no coil bind.
2. Start with approximately 2 mm compression and at least 3 mm remaining stroke. Verify paper force is suitable for the chosen pen.
3. Draw repeated 40 mm squares and circles inside the 60 mm region using known coordinates. Record closure error, repeatability and paper damage before enabling vision.

## Software consequences and next stage

Set paper size to measured dimensions, independent of draw-region size. Use a 60 mm drawing square centered on the note. Four ArUco markers go on the surrounding rigid board, not inside the small note. Marker-to-note position is fixed by the holder only after calibration.

Constrained IK remains base yaw plus planar shoulder/elbow plus compensating wrist pitch. Tool roll is an independent fixed angle during drawing, provided the roll axis and pen axis are coaxial. Recalibrate tool length for each installed module. Use measured joint travel and collision validation, not assumed 0–180 degree mechanical travel.

Next release: measured servo envelopes, complete supported joint geometry and horn adapters, base/shoulder/link CAD, assembly-specific hardware schedule and collision-checked motion envelope. Do not order all final screw lengths or print the full arm from this preliminary package. STEP and complete assembly files are not included in this fit-test release.

## Reference specifications

- https://towerpro.com.tw/product/mg996r/ — nominal MG996R body, mass and stall torque. Manufacturer distinguishes positional travel variants.
- https://towerpro.com.tw/product/mg90s-3/ — nominal MG90S body and mass. Verify the actual owned units and supply rating.
- https://learn.adafruit.com/16-channel-pwm-servo-driver/hooking-it-up — separate logic and servo power wiring.

These sources were inspected during phase 1. Their figures are reference inputs, not measurements of the user's hardware.

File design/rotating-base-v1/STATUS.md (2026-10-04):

> SUPERSEDED — DO NOT PRINT OR BUY FROM THIS PACKAGE.
> The compact-base-review revision replaces this tall prototype. See outputs/CURRENT_BUILD_STATUS.md. Existing fit-test results remain valid.
# Stage status

Completed digitally: seven printable part types, parameterized OpenSCAD source, stationary frame and rotating platform assembly preview, exploded view, hardware schedule, assembly order, mesh validation and selected analytical clearance checks.

Physical basis: the user accepted the prior servo mounting plates and the one-bearing carrier/cap fit. The carrier/cap geometry is reused unchanged.

Not yet validated: shaft fit, platform clamp, frame stiffness, two-bearing alignment, bearing axial retention under actual arm load, or thermal/torque performance. No loaded or powered test has been performed.

Pending input: identify the supplied MG90S horn (double-ended, cross-shaped or single-ended) and verify its usable attachment-hole geometry before releasing the motor coupling. A photo of the actual horn will be useful for the attachment layout; no motor adapter is included in this release.

Design departure: the prototype platform sits approximately 142 mm above the board. Shoulder-axis height and the original 60 mm drawing patch must be revalidated with the eventual shoulder carrier. This is a mechanical base prototype, not a finalized full-arm workspace layout.

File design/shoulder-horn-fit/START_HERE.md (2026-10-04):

# Shoulder horn fit check (unpowered)

Print ONLY `01_shoulder_hub.stl`: one copy, flat as exported, PLA, 0.12 mm layers, 4 walls, 40% infill, no supports.

This is the real shoulder drive hub, not a throwaway coupon. It bolts to the MG996R's double-arm horn. Later, the upper arm bolts to it with four M3 screws into the hex nut pockets on its underside.

## Check (servo unplugged, no screws yet)

1. Hold the horn under the hub, with the **hex pockets facing the horn**. Center the horn's middle screw in the hub's big center hole.
2. Turn the horn until its two arms line up under one pair of **opposite slots**. On each arm, at least one horn hole should be fully visible through the slot, at about the same distance from the center on both sides.
3. The hub should sit **flat** on the horn, not rocking.
4. Put the horn back on the MG996R shaft (gently, don't twist the shaft) and hold the hub on top.
   - Can you reach the horn's center screw through the hub's center hole?
   - Does the hub clear the servo case all the way around?

## Report

"holes line up, sits flat, clears case", or which check fails. A photo helps if something is off.

Also tell me whether the MG996R came with any other horns (round disc, cross, single arm), and what small screws came with it.

## Later (not yet)

- Horn to hub: two of the horn's small supplied screws, down through the slots. The counterbores leave 2.5 mm of plastic under the screw heads, so short screws reach.
- Upper arm to hub: four M3 screws into M3 nuts pressed into the hex pockets.

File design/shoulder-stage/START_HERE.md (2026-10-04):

# Stage 5: shoulder mount + load test

Build the MG996R shoulder on the turntable with a 120 mm **test arm**, then check that the servo can hold the weight of a full arm without sagging or overheating. This is the shoulder load test from the original spec. Nothing in the real arm gets printed until this passes.

- `everything_so_far.png`: the whole robot so far, assembled and labeled
- `construction_diagram.png`: exploded view, every part numbered in build order (use this one)
- `servo_orientation.png`: which way round the MG996R goes (its shaft is off-center)
- `screw_map.png`: every screw, lettered A-G, with what it passes through and how many
- `assembly_preview.png`: what it looks like built
- `assembly_stack_diagram.png`: schematic top view of the stack

## Print

All PLA, your 0.12 mm profile, 100% scale, flat as exported, no supports.

| File | Qty | Settings |
|---|---:|---|
| 02_shoulder_carrier.stl | 1 | 5 walls, 40% infill. Prints standing up (base plate on the bed). |
| 03_bearing_housing.stl | 1 | 4 walls, 40% |
| 04_bearing_cap.stl | 1 | 4 walls |
| 05_lever_cheek_A_hub_side.stl | 1 | 4 walls, 40% |
| 06_lever_cheek_B_bearing_side.stl | 1 | 4 walls, 40% |
| 07_lever_rung_PRINT_3.stl | **3** | 4 walls, 40% |
| 08_axle_spacers.stl | 1 | 100% infill (6 small rings) |

You already have `01_shoulder_hub` from the horn fit check.

## Hardware

| Item | Qty | Used for |
|---|---:|---|
| M3 × 16 screw + nut + washer | 4 | carrier to platform (same holes as the pointer) |
| M3 × 16 screw + nut + washer | 4 | servo tabs to carrier |
| M3 × 20 screw + washer | 4 | cap + housing into the carrier's back wall (screws thread into the plastic, no nuts) |
| M3 × 12 screw + nut | 4 | cheek A to hub (nuts press into the hub's hex pockets) |
| M3 × 16 screw + nut | 6 | rungs to cheeks (nuts drop into the rung slots) |
| **M5 × 30 bolt** + M5 nut + M5 washer | 1 | shoulder stub axle on the bearing side |
| 625 bearing | 1 | from your spares |
| Horn screws (came with the MG996R) | 2 | horn to hub |

**M5 × 30:** if you only have the long M5 × 80, it works for this test; the extra length just sticks out sideways.

For the load test you also need an empty water bottle, string or a zip tie, a measuring cup (1 mL of water = 1 g), and something to act as a catch under the arm (a box or a stack of books).

## Before you start

- **Secure the base to the table** with clamps or lots of strong tape. The test arm plus weight can tip the robot over.
- Remove the calibration pointer from the platform.
- Plug the MG996R into **channel 1** on the driver board (the next column over from the base servo), brown wire to the board edge.

## Build order (the order matters)

1. **Carrier onto the platform.** Use the same 4 holes and screws as the pointer. Either direction works; the easy way is screws up from below with the nuts on top, like you did for the pointer. See `carrier_on_your_photo.png`. Do this before anything else; the servo covers two of the screws.
   **Then aim it at the sticky note.** The carrier sits a quarter turn from where the calibration pointer sat, so the arm would point sideways. With the power off, loosen the 4 motor-plate nuts and slide the plate back until the gears separate. Don't turn the small gear. Turn the platform by hand until the carrier's short end (where the arm will stick out) faces the sticky note. Slide the plate back in to re-mesh and tighten the nuts. See `everything_so_far.png`.
2. **Bearing side.** Press the bearing into the housing pocket. Put one 1 mm spacer on the M5 bolt, then push the bolt through the bearing from the housing's flat side (the side without the pocket), so the head ends up on the flat side. Put the cap over the pocket. Hold the housing against the back wall's outer face (the bolt head goes into the big hole, threads pointing out), and thread in the 4 × M3 × 20 with washers. **Leave them slightly loose** so the housing can still slide a little.
3. **Center the servo.** Upload `shoulder_test/shoulder_test.ino`, plug in the adapter, and type `c`. The MG996R goes to its center. Then type `o` and unplug the adapter.
4. **Servo into the carrier.** The shaft is near one end of the servo body, not in the middle; see `servo_orientation.png`. Slide the body through the window from the hub side (the side away from the back wall), shaft pointing away from the back wall. Turn it so the **shaft end faces the SHORT end of the base plate** and the shaft lines up with the big round hole in the back wall. Check from the hub side, looking square on: the shaft (or the hub's center screw) should sit directly above the round hole in the middle of the base plate, not off to one side. The cable comes out at the shaft end on this servo. Bolt the tabs with 4 × M3 × 16, nuts on the inside.
5. **Hub onto the servo.** Press 4 M3 nuts into the hub's hex pockets first. Screw the horn to the hub (2 horn screws through opposite slots). Press the horn onto the shaft so the hub's small top dot points **up and forward**, about 45°. The arm should point about 45° up when the servo is centered. Put the center screw in through the hub.
6. **Build the test arm.** Drop an M3 nut into each rung-end slot. Screw all 3 rungs to cheek A (M3 × 16).
7. **Arm onto the hub.** Hold cheek A against the hub and screw it on with 4 × M3 × 12 into the hub nuts. The arm should point forward and up.
8. **Cheek B.** Slide spacers onto the M5 bolt until they fill the gap between the bearing and cheek B (start with the 8 mm + 1 mm). Fit cheek B over the bolt and screw it to the 3 rungs. Add the M5 washer and nut outside and tighten.
9. **Line up the bearing.** Swing the arm to horizontal by hand (gently). Now tighten the 4 housing screws. Cheek B is narrow so you can reach them. The housing shifts itself into line with the servo shaft as you tighten.

**Check:** power on, `c`, then `1300` and `1700`. The arm swings smoothly with no binding or creaking. If it binds, loosen the housing screws, run `c` again, and re-tighten.

## Load test

**Setup.** Put the catch (a box) under the arm tip, about 1 cm below horizontal, so the arm lands on it if power drops. Stand a tape measure upright next to the end rung to watch for sag.

1. Power on, type `c`. Use `+` / `-` to make the arm **exactly horizontal** (a phone level app on the arm helps). Write down that pulse.
2. Tie the empty bottle to the hole in the **end rung** with string or a zip tie.
3. For each step: add water, return to the horizontal pulse, type `t` to start the timer, and watch the arm tip on the tape measure.

| Step | Bottle + water | Hold |
|---|---:|---|
| 25% | 55 g | 30 s |
| 50% | 150 g | 30 s |
| 75% | 250 g | 30 s |
| 100% | 345 g | 2 min, then 10 min if everything is fine |

(A typical empty bottle weighs about 10 g, so 345 g is about 335 mL of water.)

**Stop immediately** (lower the arm onto the catch with `-`/`+`, then `o`) if:
- the servo gets **hot**. Warm is okay; too hot to keep a finger on means stop. An infrared thermometer is better if you have one: stop at 45 °C.
- it **buzzes loudly**, jitters, or the arm creeps down.
- the arm tip sags more than **about 2 mm** from where it started (about 1°).
- the voltage at the green terminal drops below **4.8 V** (measure it during the 100% hold).

**Pass:** 100% held for 10 minutes: no stop condition, sag under about 2 mm, servo no more than warm.

## Report back

- The horizontal pulse
- For each step: did it hold? Any sag (tape reading start and end)?
- How warm the servo got at 100% after 2 min and after 10 min
- Voltage at the terminal during the 100% hold

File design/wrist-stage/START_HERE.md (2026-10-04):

# Stage 7: wrist and pen holder

A small MG90S at the end of a new forearm tilts a pen holder, so the pen can stay straight up and down whatever the arm is doing. The Sharpie slides freely in the holder: when the robot lowers it onto the paper, the pen rides up a few millimeters and presses on the paper with just its own weight. A collar stops it falling out.

Pictures in this folder:

- `after_this_stage.png`: the whole robot with the pen on the sticky note
- `construction_diagram.png`: exploded view, numbered in build order
- `screw_map.png`: every screw, lettered, with what it passes through

## Print

All PLA, your 0.12 mm profile, 100% scale, flat as exported, no supports.

| File | Qty | Settings |
|---|---:|---|
| 12_forearm_cheek_A_hub_side.stl | 1 | 4 walls, 40% |
| 13_forearm_cheek_B_bearing_side.stl | 1 | 4 walls, 40% |
| 14_wrist_bracket.stl | 1 | 3 walls, 20%. Stands on its thick end plate, 53 mm tall. |
| 15_pen_holder_arm_A.stl | 1 | 4 walls, 40% |
| 16_pen_holder_body.stl | 1 | 3 walls, 15%. The pen hole runs sideways and has a pointed top on purpose, so it prints without supports. |
| 17_pen_collar.stl | 1 | 4 walls, 40% |
| 18_pivot_sleeve.stl | 1 | 100% infill (tiny tube) |

The test arm's cheeks and two of its rungs retire. Keep **one rung** (with its nuts): it goes into the new forearm.

## Hardware

- One MG90S from your box, with its bag (horn, horn screws, center screw, 2 tab screws)
- New: M3 × 16: 5, M3 × 12: 3, M3 nuts: 8, M3 washer: 1
- Reused: the 4 × M3 × 12 that held the test arm to the elbow hub, the rung's 2 screws, the elbow's M5 washer and nut
- 3 male-to-female jumper wires (your ELEGOO kit) to extend the MG90S cable, which is too short to reach the driver board

## Wiring and program

- Extend the MG90S cable with the 3 jumpers, matching colors, and plug it into **channel 3** (next to the elbow), brown toward the board edge.
- Upload `arm_test/arm_test.ino` from this folder. It drives four joints: `b` base, `s` shoulder, `e` elbow, `w` wrist. The wrist is limited to 1350-1650 until we know which way it turns. The elbow now stops at 1900 so the new forearm can't fold into the upper arm.

## Build order (numbers match construction_diagram.png)

**1. Take the test arm off the elbow**, the same way you took it off the shoulder: M5 nut off, cheek B's 3 rung screws out, cheek B off, then the 4 screws holding cheek A to the elbow hub. Keep one rung and all the screws.

**Steps 2-7 happen on the table, on the wrist bracket alone.**

2. Find the bracket's two walls: the **tab wall** has the rectangular window, the **back wall** has a small slot-shaped hole.
3. Plug the MG90S into channel 3, power on, type `w1500`, then `wo`, and unplug. It is now centered. Slide it into the window from the side away from the back wall. Shaft points **away from the back wall**, and the shaft end goes toward the **open end** of the bracket, away from the thick end plate. Two tab screws into the wall.
4. Horn onto the shaft. Pen-holder arm A goes on the horn: counterbored face outward, 2 horn screws through opposite slots. Turn the horn so arm A's wide end points **straight along the bracket, away from the end plate**. Then the center screw.
5. Drop an M3 nut into the slot-shaped pocket on the servo side of the back wall. Drop 2 M3 nuts into the slots on the long sides of the pen-holder body, near the top.
6. Push the pivot sleeve through the hole in the body's arm B, then hold the body so arm B sits outside the back wall and the sleeve goes into the slot.
7. M3 × 16 with the washer through the sleeve into the nut. **Leave it loose.** Bring the body up against arm A and screw them together with 2 × M3 × 12. Wiggle the holder up and down a few times, then tighten the pivot screw.

**Steps 8-10 put it on the arm.**

8. Rung onto forearm cheek A, in the hole near the round end (M3 × 16).
9. Drop 4 M3 nuts into the 4 slots at the ends of the bracket's thick end plate. Hold the bracket against cheek A with the **MG90S horn side facing cheek A**. Two M3 × 16 through cheek A into the end plate. Then cheek A onto the elbow hub with the 4 × M3 × 12, forearm pointing **straight down when the upper arm is level**, like the test arm was.
10. Spacers on the elbow bolt, cheek B over it, then 3 screws into cheek B: one into the rung, two into the end plate. Elbow M5 washer and nut back on.

**Steps 11-12: the pen.**

11. Nut into the collar's side slot, M3 × 12 started in it. Slide the collar onto the Sharpie (cap off), about halfway up.
12. Drop the pen tip-first down through the holder, from the side where the collar will rest. Slide the collar until about **1 inch of pen** sticks out of the bottom of the holder, and tighten the collar screw just snug.

**Check:** push the pen tip up gently with a finger. It should slide up and drop back by itself, without catching.

## First power-on

Base clamped. Support the forearm with your hand at first.

1. `s1500`, then raise the shoulder in steps: `s1400`, `s1300`, `s1200`, `s1100`.
2. `e1500`. The forearm hangs at a right angle to the upper arm.
3. `w1500`. The pen lines up with the forearm.
4. Try `w1450` and `w1550`. **Which one tilts the pen tip forward**, away from the base toward the sticky note?

Stop (`o`, arm supported) if anything rubs, buzzes loudly or heads for the table.

## Report back

- Which wrist number tilts the pen tip forward: `w1450` or `w1550`?
- Does the pen slide freely in the holder?
- Anything rubbing? A photo of the wrist helps.

Next comes calibration: teaching the software the exact angle each servo pulse gives, then the first drawn square.

## What was checked in CAD (not yet on the real robot)

- All 7 parts are single, watertight solids and fit the A1 mini bed.
- Pen holder vs the wrist bracket and servo: clear from -75 to +45 degrees of wrist turn.
- Pen (full 125 mm Sharpie) vs the forearm: clear from -75 to +15 degrees. Drawing needs -11 to -42.
- New forearm vs upper arm: clear from +20 down to -125 degrees of elbow; touches at -140, hence the 1900 limit.
- Drawing poses (pen on the paper and 25 mm above it, near and far edges of the sticky note): the arm clears the shoulder mount and the table.
- MG90S size, shaft position and horn height are estimates. The pivot slot gives the holder about 1.5 mm of adjustment to line up with the real shaft.

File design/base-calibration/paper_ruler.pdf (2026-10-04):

# Paper ruler for the base calibration

Print at "Actual size" / 100% (not "Fit to page"). Cut out one strip and tape it under the pen.

Check: the bar below should measure 85.6 mm, the same width as a credit card.

0 | 1 | 2 | 3 | 4 | 5 | 6 | 7 | 8 | 9 | 10 11 12 13 14 15 16 17

cm

0 | 1 | 2 | 3 | 4 | 5 | 6 | 7 | 8 | 9 | 10 11 12 13 14 15 16 17

cm

0 | 1 | 2 | 3 | 4 | 5 | 6 | 7 | 8 | 9 | 10 11 12 13 14 15 16 17

cm

Three copies in case one gets cut wrong. Numbers are centimeters; small ticks are millimeters.

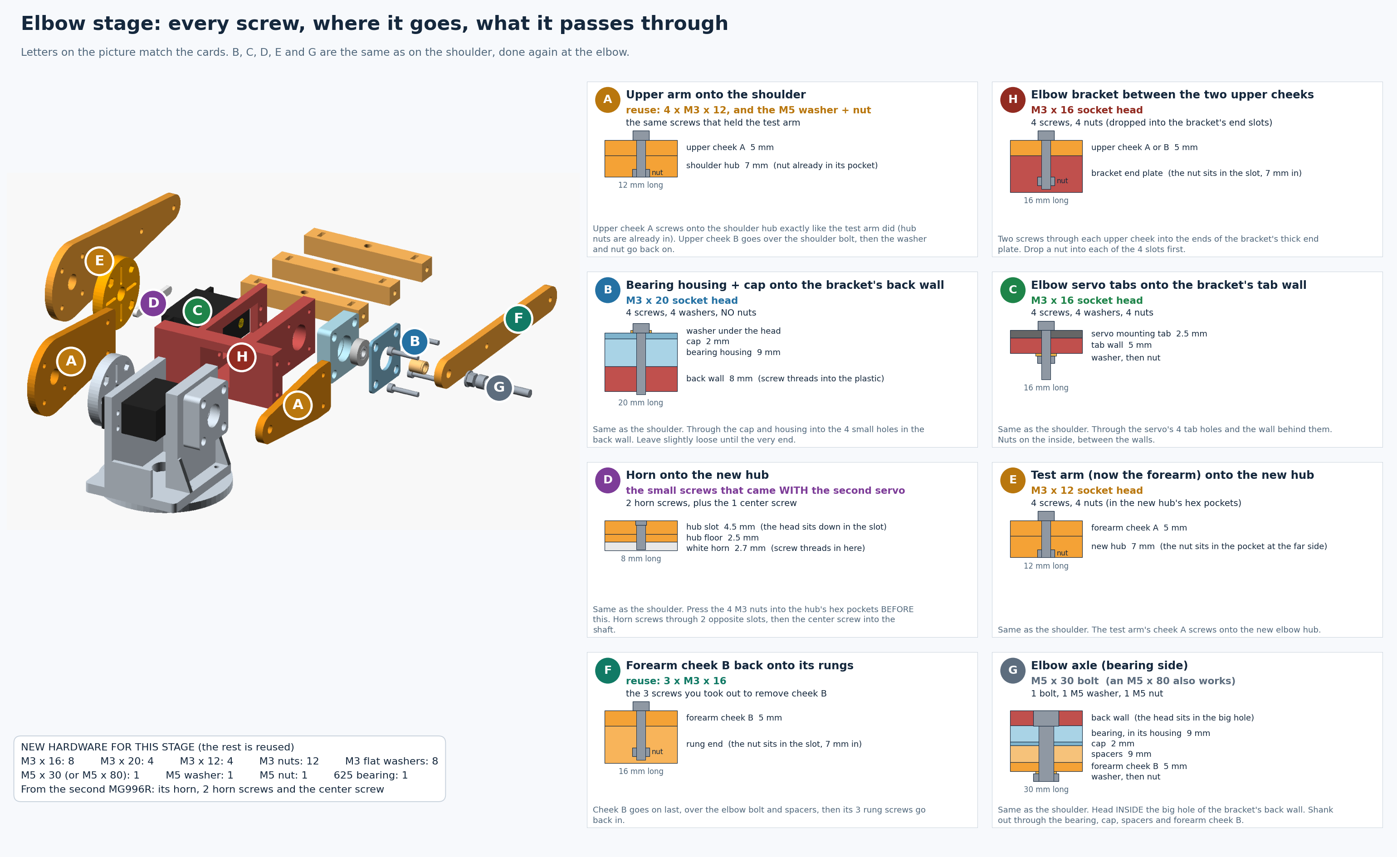
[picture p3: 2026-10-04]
design/elbow-stage/screw_map.png

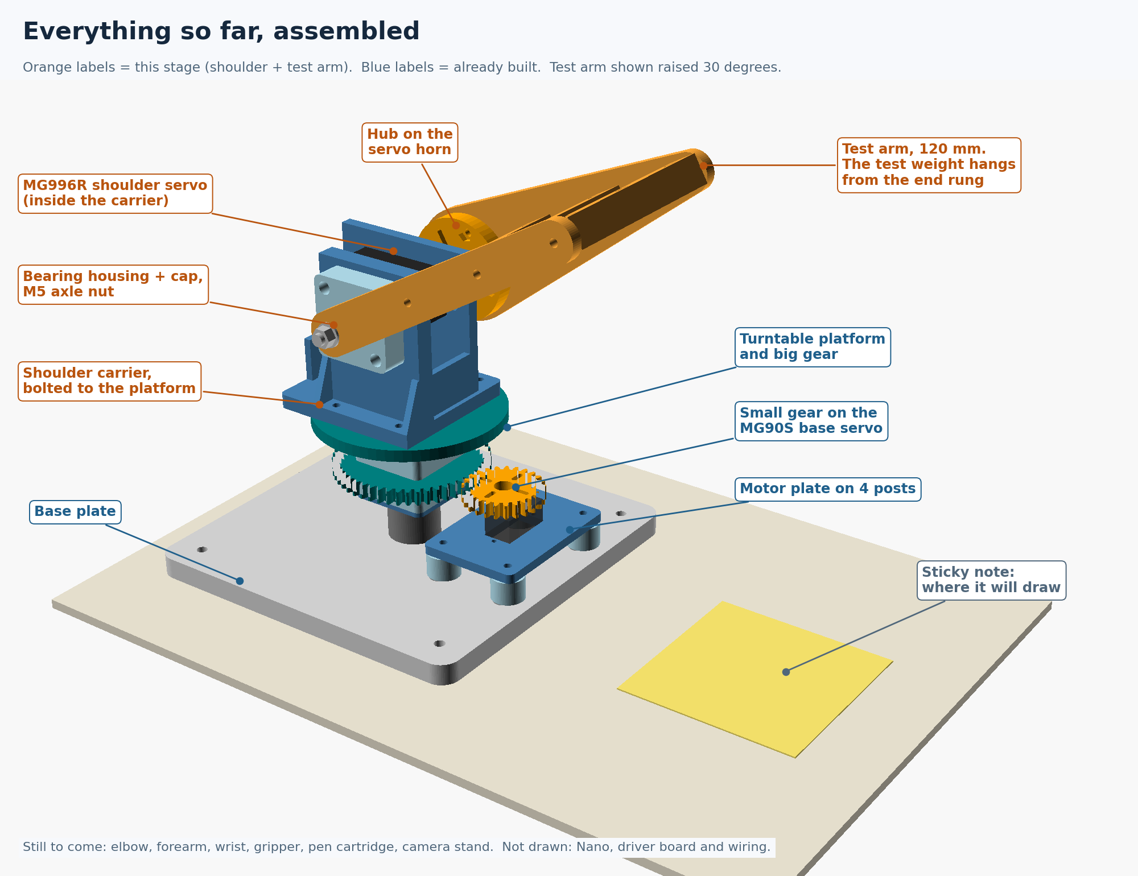
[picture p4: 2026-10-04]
design/shoulder-stage/everything_so_far.png

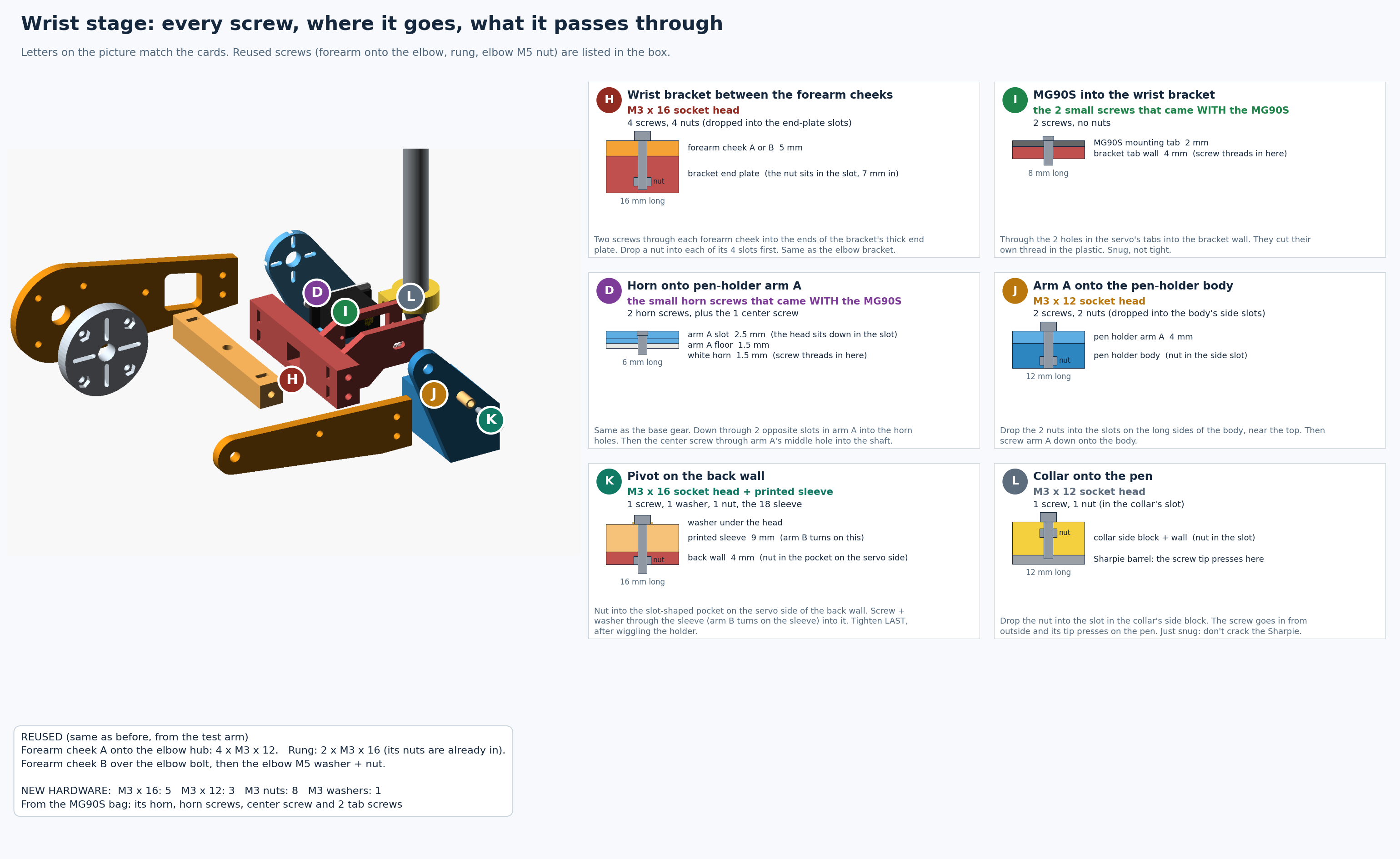
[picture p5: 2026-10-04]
design/wrist-stage/screw_map.png

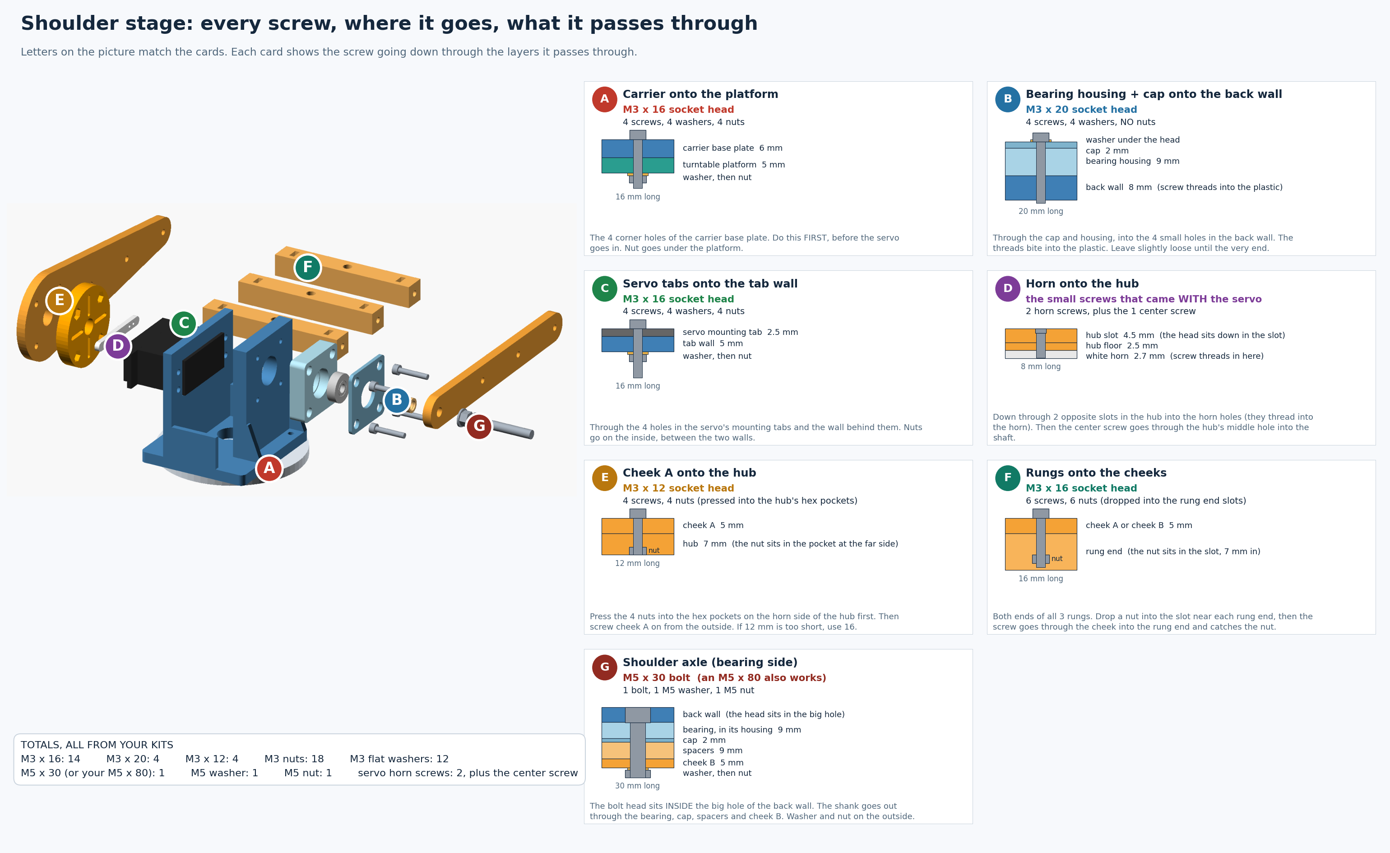
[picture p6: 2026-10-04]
design/shoulder-stage/screw_map.png

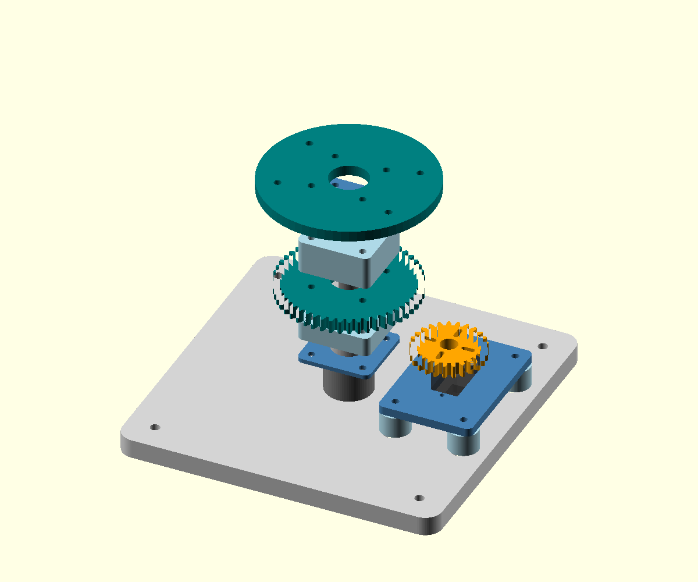
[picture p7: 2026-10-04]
design/compact-base-stage-1/exploded_preview.png

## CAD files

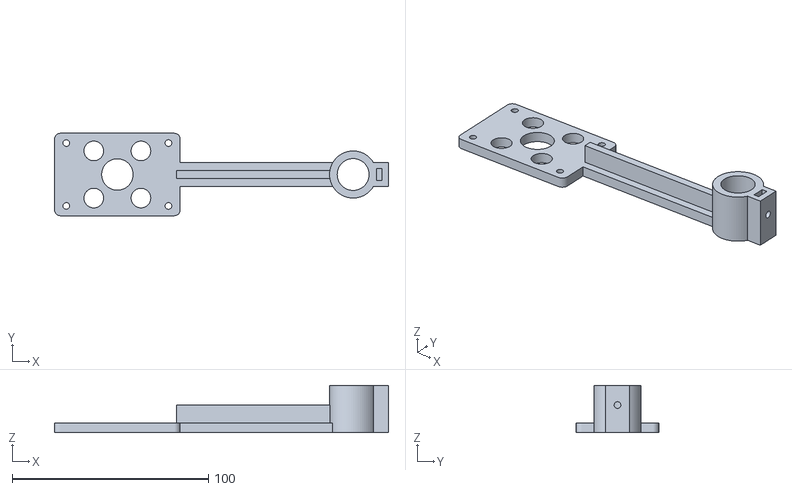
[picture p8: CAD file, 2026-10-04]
design/base-calibration/calibration_pointer.stl
170.0 x 42.0 x 24.0

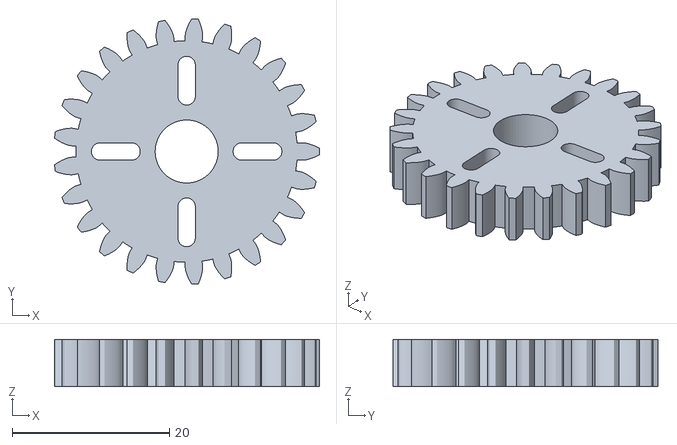
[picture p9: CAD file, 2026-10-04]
design/base-horn-fit/01_motor_gear_fit.stl
33.7 x 33.7 x 6.00

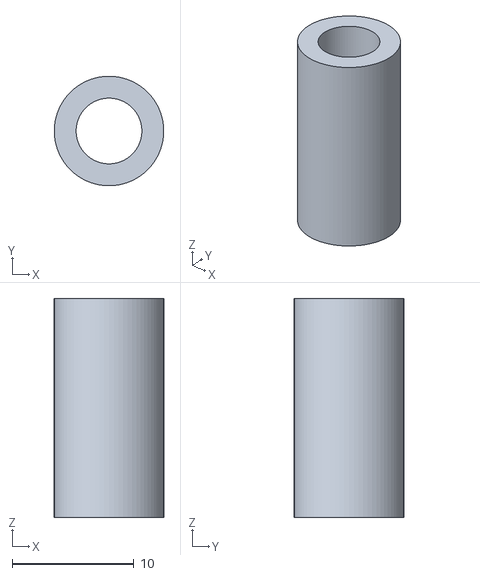
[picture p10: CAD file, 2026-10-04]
design/compact-base-stage-1/08_inner_spacer_18mm.stl
9.00 x 9.00 x 18.0

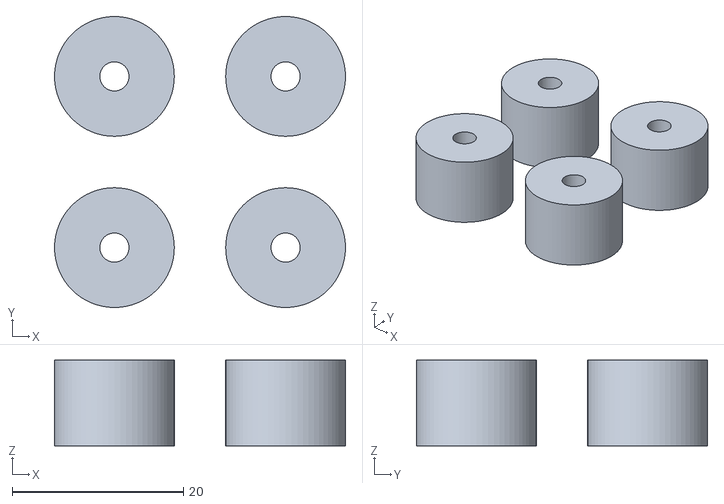
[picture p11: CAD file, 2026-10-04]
design/compact-base-stage-2/posts_set_of_4.stl
34.0 x 34.0 x 10.0

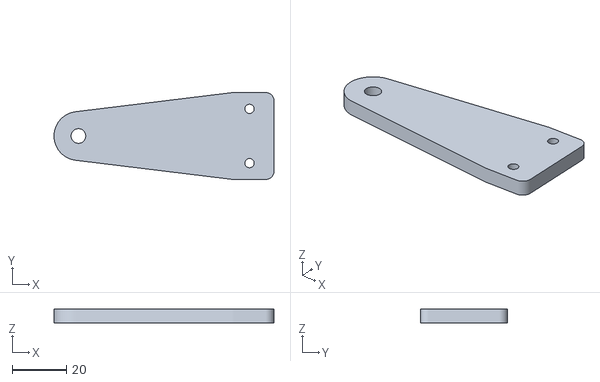
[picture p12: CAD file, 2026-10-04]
design/elbow-stage/11_upper_cheek_B_bearing_side.stl
81.0 x 32.0 x 5.00

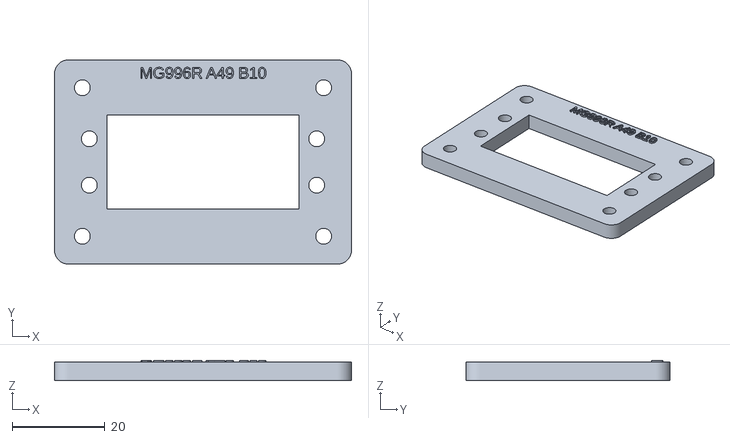
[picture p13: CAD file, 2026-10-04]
design/mechanical-fit-v1/02_mg996r_mount_plate.stl
64.0 x 44.0 x 4.40

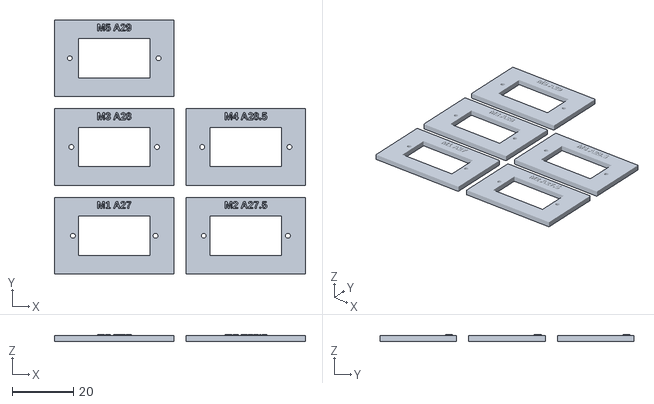
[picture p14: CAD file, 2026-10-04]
design/mounting-templates/mg90s_mounting_templates.stl
82.0 x 83.0 x 2.40

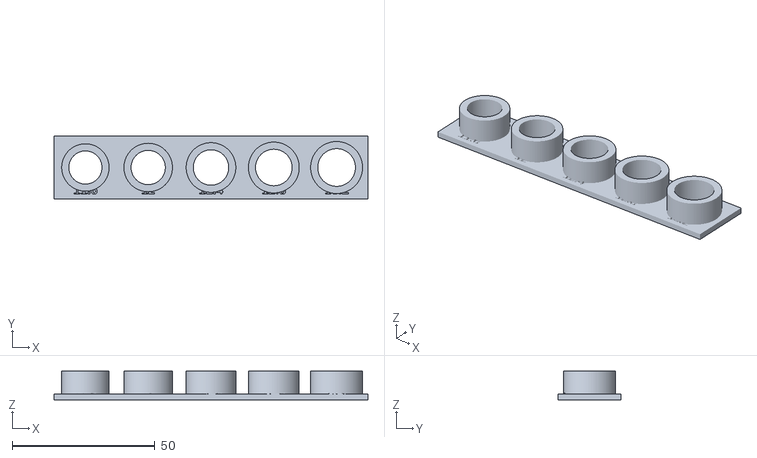
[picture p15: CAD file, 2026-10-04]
design/pen-fit/pen_fit.stl
110.0 x 22.0 x 10.0

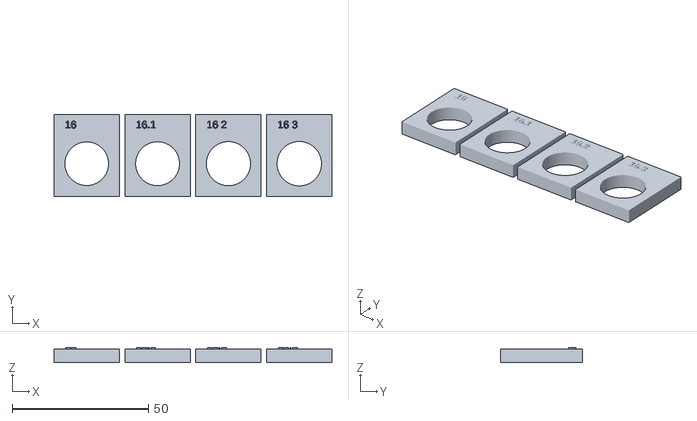
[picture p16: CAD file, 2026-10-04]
design/phase-2/bearings.stl
102.0 x 30.0 x 5.50

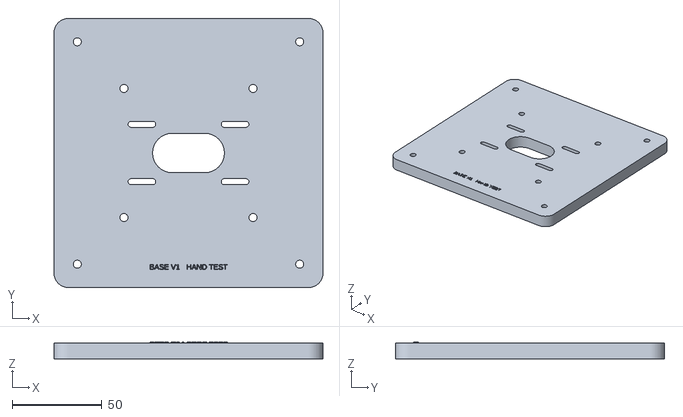
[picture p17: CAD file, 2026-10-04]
design/rotating-base-v1/01_base_v1.stl
150.0 x 150.0 x 9.40

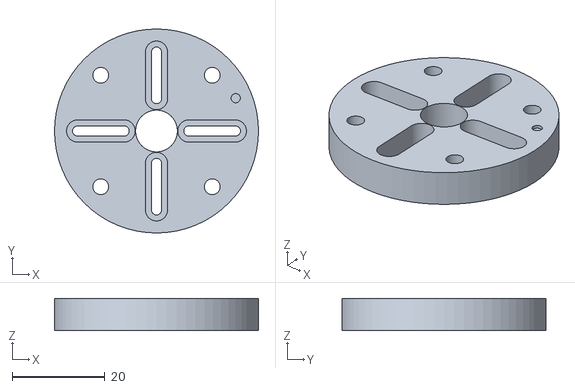
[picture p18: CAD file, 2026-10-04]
design/shoulder-horn-fit/01_shoulder_hub.stl
44.0 x 44.0 x 7.00

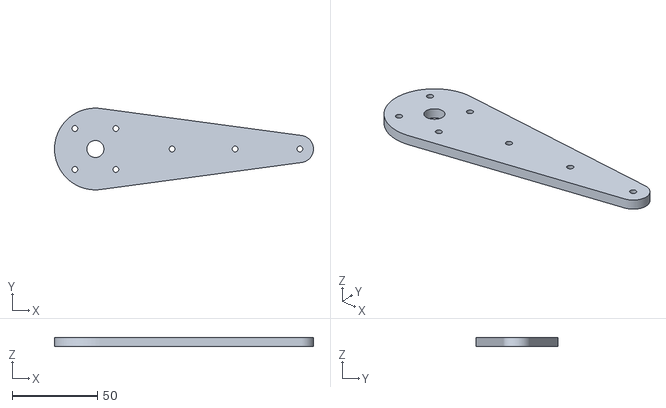
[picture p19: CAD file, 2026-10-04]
design/shoulder-stage/05_lever_cheek_A_hub_side.stl
152.0 x 48.0 x 5.00

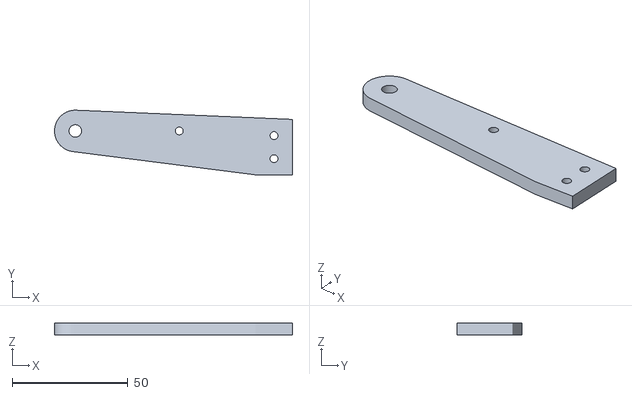
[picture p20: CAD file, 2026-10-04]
design/wrist-stage/13_forearm_cheek_B_bearing_side.stl
103.0 x 28.0 x 5.00

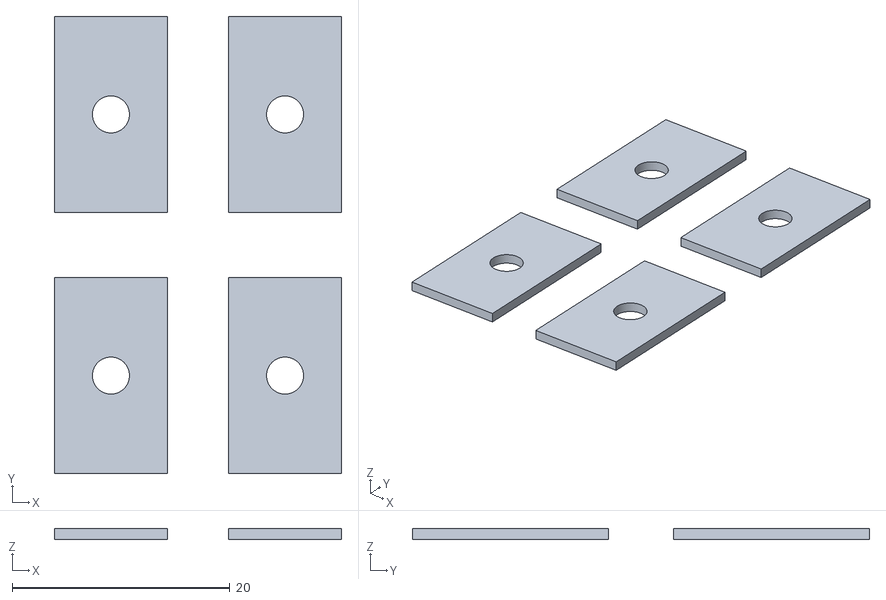
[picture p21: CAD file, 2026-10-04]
PRINT-NEXT-MOTOR-MOUNT/02_PRINT_ONCE_four_backing_plates.stl
26.4 x 42.0 x 1.00

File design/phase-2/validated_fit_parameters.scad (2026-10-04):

// Physical coupon results 2026-09-24; Generic PLA, A1 mini profile,
// 0.4 mm nozzle, 0.12 mm layers, 0.20 mm first layer.
// These are fit parameters, not a complete or validated assembly.
servo_body_extra_total = 0.6;
mg90s_reference_body_xy = [22.8, 12.2];
mg996r_reference_body_xy = [40.7, 19.7];
mg90s_opening_xy = mg90s_reference_body_xy + [servo_body_extra_total,servo_body_extra_total];
mg996r_opening_xy = mg996r_reference_body_xy + [servo_body_extra_total,servo_body_extra_total];
bearing_625_bore_d = 16.3;
slider_clearance_per_side = 0.3; // user-selected coupon fit; validate final loaded guide
note_nominal_xy = [76.2,76.2]; // holder fit accepted; actual note size unmeasured
// User-selected mounting templates; nominal center spacings, not caliper precision.
mg90s_mount_pitch_a = 27; // M1
mg996r_mount_pitch_a = 49; // S2, lengthwise
mg996r_mount_pitch_b = 10; // S2, across each end tab

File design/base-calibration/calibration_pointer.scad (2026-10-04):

// Base calibration pointer: bolts to the rotating platform's four arm holes
// (+/-26, +/-16) and holds a pen vertically at 120 mm from the base axis.
// Origin = base axis at the platform top surface. Millimeters.
// Print flat as exported: 100% scale, PLA, 4 walls, 30% infill, no supports.
part="pointer";
tip_radius=120;
$fn=64;

module rrect(x0,x1,y0,y1,h,r=3){
  linear_extrude(h) hull() for(x=[x0+r,x1-r],y=[y0+r,y1-r]) translate([x,y]) circle(r=r);
}

module pointer(){
  difference(){
    union(){
      rrect(-32,32,-21,21,5);                              // mount plate
      translate([20,-6,0]) cube([tip_radius-20,12,5]);     // arm
      translate([30,-2,5]) cube([tip_radius-40,4,9]);      // stiffening rib
      translate([tip_radius,0,0]) cylinder(d=24,h=24);     // pen sleeve
      translate([tip_radius+8,-6,0]) cube([10,12,24]);     // set-screw boss
    }
    for(x=[-26,26],y=[-16,16]) translate([x,y,-1]) cylinder(d=3.4,h=7);   // M3 to platform
    for(x=[-12,12],y=[-12,12]) translate([x,y,-1]) cylinder(d=10,h=7);   // turntable bolt heads
    translate([0,0,-1]) cylinder(d=16,h=7);                               // axle nut stack
    translate([tip_radius,0,-1]) cylinder(d=16.2,h=26);                   // pen bore
    translate([tip_radius,0,14]) rotate([0,90,0]) cylinder(d=3.4,h=30);   // set screw
    translate([tip_radius+12,-3.1,10.7]) cube([2.8,6.2,20]);              // M3 nut slot
  }
}

if(part=="pointer") pointer();

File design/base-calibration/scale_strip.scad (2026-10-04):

// Millimeter scale strip for reading the calibration pen tip. 0-160 mm.
// Lay flat on the table under the pen, ticks up. Print flat, no supports.
// Resin gives the crispest ticks; FDM works at 0.12 mm layers.
$fn=32;
len=160;
difference(){
  translate([-5,0,0]) cube([len+10,24,2]);
  for(i=[0:len]){
    h = (i%10==0) ? 10 : (i%5==0) ? 7 : 4;
    translate([i-0.225,24-h,1.4]) cube([0.45,h+1,1]);
  }
  for(i=[0:10:len])
    translate([i,4,1.4]) linear_extrude(1)
      text(str(i/10), size=4.5, halign="center", font="Liberation Sans:style=Bold");
}

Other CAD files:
PRINT-NEXT-MOTOR-MOUNT/ALREADY-PRINTED-REUSE/MG90S_mount_plate_PRINT_ONE_ONLY_IF_MISSING.stl
design/base-calibration/scale_strip.stl
design/compact-base-stage-1/01_base.stl
design/compact-base-stage-2/motor_mount.scad
design/base-horn-fit/compact_base.scad
design/base-horn-fit/gear_profiles.scad
design/compact-base-review/compact_base.scad
design/compact-base-review/gear_profiles.scad
design/compact-base-stage-1/02_fixed_pedestal.stl
design/compact-base-stage-1/03_lower_rotor.stl
design/compact-base-stage-1/04_large_gear.stl
design/compact-base-stage-1/05_upper_rotor.stl
design/compact-base-stage-1/06_bearing_cap.stl
design/compact-base-stage-1/07_top_platform.stl
design/compact-base-stage-1/09_top_spacer_10mm.stl
design/compact-base-stage-1/compact_base.scad
design/compact-base-stage-1/gear_profiles.scad
design/elbow-stage/03_bearing_housing_PRINT_1_MORE.stl
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

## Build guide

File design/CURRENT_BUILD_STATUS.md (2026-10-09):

# Current build status — 9 October 2026

FIRST DRAWING DONE (9 Oct): outputs/drawing/draw/draw.ino (IK, commands h d u t q l r ? o) drew a 40 mm square on the note; user: "works perfectly". Calibration from 3 measured poses is in outputs/calibration/measurements.md: shoulder axis 127 mm, pen tip 67 mm below the wrist axis, shoulder_us = 1495 - 13.9*s, elbow_us = 1500 - 10.7*(e + 58.5), wrist_us = 1450 - 10.2*(w + 56.2). The near side of the note needs elbow to about 2130 and wrist to about 905. User checked clearance; limits are now elbow 950-2200, wrist 880-1700 (arm_test.ino and draw.ino). Note center 166 mm (6 1/2 in) straight out from the turntable. Next: more shapes or text, push to GitHub (ask first), then camera stand + vision.

Wrist stage BUILT per user (6 Oct). CORRECTED wrist direction: LOWER pulse turns the pen toward vertical (negative wa, the drawing side); higher pulse swings the tip out (positive wa, collides past about +15 deg). At s1300/e1500 the pen is vertical near w1350, but that pose is too low: the holder sits on the table (wrist axis about 40 mm up, holder reaches 52 mm below it). Use s1100 or higher for vertical-pen tests (wrist axis about 94 mm up, tip about 14 mm above the table). arm_test.ino wrist limits now 950-1600. Part 16 was reprinted after the mirror-image bug. Pen does not drop back freely (user: somewhat firm); retest with the pen vertical, then ease the bore if needed.

Elbow stage PASSED per user (3 Oct): assembled, forearm sits at a right angle on e1500, moves smoothly. Elbow direction: LOWER pulse (e1400) swings the forearm forward/up, toward straight. Base, shoulder and elbow are all built and driven by arm_test.ino.

Pen fit: Sharpie Fine slides best in the 12.4 mm ring (user, 3 Oct).

Current action: wrist-stage/START_HERE.md. New forearm (cheeks 12/13 + one old rung), MG90S wrist bracket (14) bolted between the cheek ends, pen holder (15 arm A on the horn, 16 body with a 12.4 teardrop bore riding on an M3 pivot + printed sleeve 18), collar (17). Tool geometry: pen tip 80 mm from the wrist axis along the pen, pen axis offset 25 mm forward. IK with L1=L2=120, shoulder 115 mm above the table: drawing patch (r 135-197, z 0-25) needs shoulder 32-57 deg, elbow -87 to -125, wrist -11 to -42. CAD checks: tool clear -75..+45, pen clear -75..+15, forearm vs upper arm clear +20..-125 (contact at -140), drawing poses clear of mount and table. Wrist on channel 3; arm_test.ino (wrist-stage) limits wrist to 1350-1650 and elbow to 1900 max. Power: user keeps the 3 A adapter for now; upgrade to 5 V 10 A if the terminal sags below 4.8 V or when the gripper servo is added.

Shoulder stage PASSED per user (2 Oct): assembled, moves smoothly, shoulder center (1500 us) = arm straight forward (horizontal), load test "all good" through 345 g at 120 mm (about 4.6 kgf cm with the lever). Shoulder direction: LOWER pulse raises the arm (1400 = up). arm_test.ino limits the shoulder to 700-1550 us. Servo temperature and supply voltage under load were not reported.

Current action: elbow-stage/START_HERE.md. New prints: 09 elbow bracket, 10/11 upper-arm cheeks, plus one more each of 01 hub, 03 housing, 04 cap, 08 spacers. The 120 mm test lever moves to the elbow and becomes the forearm. Elbow repeats the shoulder Y stack on a bracket bolted between two short upper-arm cheeks; elbow axis 120 mm from the shoulder axis. Elbow servo on PCA9685 channel 2. arm_test.ino drives b/s/e (channels 0/1/2); elbow limited to 950-2050 us.

CAD checks: forearm vs upper arm clear for elbow +20 to -140 deg (collision confirmed at 180 as a control); arm vs shoulder carrier clear for shoulder 0-120 deg. Not checked: base/motor/table, cables. Bracket is about 59 cm3 (roughly 35 g at 3 walls / 20 %); with the heavy test lever as forearm the shoulder torque at the working extreme is about equal to the tested load, so a lighter forearm is planned with the wrist stage.

Earlier results still stand: base calibrated (1500 us center, about 22.2 us per platform degree, +/-35 deg = 720/2280 us), supply 5.48 V unloaded, threaded M5 turntable axle kept by user choice.

Still pending: wrist pitch, wrist roll (optional), gripper, pen cartridge + dock, lighter forearm, camera stand, full-arm power supply sizing (three+ servos on a 3 A adapter is marginal), OE/startup-safety wiring, software.

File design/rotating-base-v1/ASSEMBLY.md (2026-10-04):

> SUPERSEDED — DO NOT PRINT OR BUY FROM THIS PACKAGE.
> The compact-base-review revision replaces this tall prototype. See outputs/CURRENT_BUILD_STATUS.md. Existing fit-test results remain valid.
# Rotating base V1 — hand-operated mechanical prototype

This stage adds a real two-bearing rotating platform. It does not yet include the servo-horn connection, powered movement, shoulder support or links. Test it by hand without the arm attached. The existing accepted MG90S plate remains the motor-mount interface for the next stage.

## How it works

Four bolted printed columns hold two stationary decks. Each deck carries one of the tested bearing carriers and caps. Both 625 bearing inner rings and a smooth vertical shaft rotate; outer rings stay in the fixed housings. The rotating platform clamps onto the shaft. Its weight travels through the shaft's upper collar and narrow washer into the upper bearing inner ring, then its outer ring and the stationary frame. The second bearing, 35 mm below the first, helps resist tilting. The lower collar prevents upward escape; it must not preload the bearings.

The drive will attach below the lower bearing. It must transmit torque while preserving axial clearance so the servo cannot take the platform weight. No drive adapter is released until the supplied MG90S horn is identified and its attachment geometry checked. Do not power a jury-rigged coupling.

This prototype uses a smooth shaft instead of treating a bolt's threads as a bearing journal. It introduces purchased shaft/collars because they provide a repeatable bearing surface and positive axial retention. None of the parts is claimed load-tested.

## Print list

| File | Copies | Orientation |
|---|---:|---|
| 01_base_v1.stl | 1 | Label upward |
| 02_bearing_deck.stl | 2 | Flat |
| 03_lower_posts_4x.stl | 1 file = 4 posts | Upright |
| 04_upper_posts_4x.stl | 1 file = 4 posts | Upright |
| 05_rotating_platform.stl | 1 | Broad round flange on bed, clamp block upward |
| 06_bearing_carrier.stl | 1 additional if your tested carrier is available | Pocket upward |
| 07_bearing_cap.stl | 1 additional if your tested cap is available | Flat |

Reuse ONE carrier and ONE cap from the successful previous test: total required is TWO of each. The carrier and cap geometry is unchanged. This base supersedes the optional mechanical-fit-v1 base for this prototype; do not stack the two bases.

Use the tested PLA, 0.4 mm nozzle, 0.12 mm layers and 0.20 mm first layer. Four walls, six top/bottom layers, 25% infill are initial settings. Print at 100% scale. No supports expected; inspect the short bridges over recessed fastener pockets and the horizontal clamp-screw hole. Clear strings without altering the bearing fit. Every individual part fits the A1 mini's 180 mm square bed. Do not shrink a crowded layout; use additional plates.

## Hardware for the hand-operated assembly

Confirm availability before printing the large frame. These dimensions are a proposed build specification; substitutions need a stack/clearance check.

| Item | Quantity | Function |
|---|---:|---|
| 625-2RS bearing, 5x16x5 mm | 2 total | Already purchased; reuse the tested one |
| Smooth precision steel shaft, nominal 5 mm diameter x 100 mm length | 1 | Rotating bearing journal; not threaded rod |
| Metal shaft collar, 5 mm bore, approximately 12 mm OD x 7 mm axial width, with retaining screw | 2 | Upper/lower axial retention |
| Narrow steel washer, 5.3 mm ID x 9 mm OD x approximately 1 mm thick | 2 | Collar contact with bearing inner ring only |
| M4 x 110 mm socket-head machine screw | 4 | Full frame columns; inspect actual threaded length |
| M4 nut | 4 | Frame retention |
| M4 washer, OD no larger than 8.8 mm and thickness no greater than 0.8 mm for bottom recess | 8 | Frame bolts, one each end |
| M3 x 20 mm machine screw | 8 | Each cap/carrier/deck stack uses four |
| M3 nut | 8 | Bearing stacks |
| Thin M3 washer | 16 | Bearing stack screws |
| M3 x 30 mm socket-head screw | 1 | Platform split clamp |
| M3 hex nut, approximately 5.5 mm across flats | 1 | Platform clamp nut trap |
| Thin M3 washer | 1 | Platform clamp screw head |
| Approximately 4 x 16 mm wood screw plus washer | 4 | Mount to an 18 mm board |

Socket heads and washers must fit recessed pockets and stay below the base bottom. Base thickness above recess = 4.2 mm, lower post 55, first deck 4, upper post 31, second deck 4, total 98.2 mm. With a bottom washer up to 0.8 mm, top washer up to 0.8 mm and approximately 3.2 mm nut, occupied length is approximately 103 mm. Actual fastener dimensions determine protrusion; require at least two full threads beyond each nut. Verify with your hardware before tightening. The corner hardware stays outside the 80 mm rotating disk sweep.

Do not substitute a large M5 washer that touches bearing seals or the outer ring. Check the narrow washer against your actual bearing inner race. Collar/washer dimensions vary; set positions physically rather than relying on the preview's exact collar coordinates. A clamp-style collar is acceptable if its envelope clears surrounding caps and platform; otherwise the specified compact set-screw style is the space budget.

## Assembly order

1. Fit one bearing into each carrier. Place the cap on top. Set each carrier on a deck, aligning the central opening and four holes on 24 mm centers. Fasten cap + carrier + deck with four M3 x 20 screws, washers and nuts. Snug evenly; verify free inner-ring rotation. These longer screws replace the M3 x 16 used for the earlier carrier-only check.
2. Insert the four M4 x 110 bolts upward through the base's OUTER frame pattern (72 x 72 mm centers), with the heads and narrow washers in the underside recesses. The inner slotted holes are reserved for the servo plate and are not frame holes.
3. On each bolt stack one 55 mm post, the lower bearing deck (bearing pocket upward), one 31 mm post, then the upper bearing deck (pocket upward). Add top washers and nuts but leave the assembly loose enough to align.
4. Pass the smooth shaft through both bearings. It should slide with gentle hand pressure. Do not hammer it. If it will not pass, stop: check shaft diameter, burrs and frame alignment. Do not enlarge the bearing inner rings.
5. With the shaft acting as an alignment reference, snug the four frame bolts progressively. Rotate the shaft after each pass. Stop if tightening introduces binding. Recheck each bearing cap; do not use nut torque to bend misaligned decks into place.
6. Above the upper bearing, put a narrow washer against the INNER ring, then an upper collar. Below the lower bearing, use the other washer and collar in reverse order. Access to the lower collar is through the open sides, under the lower deck. Secure the upper collar to the shaft. Set the lower collar with a small perceptible axial clearance, about 0.2–0.4 mm, rather than squeezing the bearings together. Secure its screw using the collar supplier's instructions.
7. Install the platform flipped relative to its print orientation: clamp block DOWN, flat disk UP. Slip its 5.2 mm clearance bore over the shaft. Fit the M3 nut in the side trap and the M3 x 30 clamp screw with washer. Position the platform clear of the upper collar; start with disk top about 142 mm above the board. Snug just enough to prevent slipping. Do not force the slit fully shut or crack the hub. The shaft may protrude above the disk; the later shoulder support must leave its center clear.
8. Rotate the platform by hand through a full turn. Check that the collar, hub, platform, caps and all screws remain clear. The final wired robot will have limited base travel; this full-turn check is for the bare mechanical assembly only.
9. Anchor the base to the board only after verifying all underside heads sit recessed and the base sits flat. Test the hand rotation again.

## Acceptance checks

- Shaft rotates freely with no new tight spots after bolting down the frame.
- Platform does not slip around the shaft with gentle hand rotation; do not apply arm-scale load yet.
- No visible rocking of bearings in their carriers or shifting of frame joints under a gentle fingertip push.
- Small axial end play remains; bearing seals do not rub printed rims or washers.
- All rotating parts clear the stationary frame and the upper collar clears the platform hub.

Report rubbing, wobble, slipping or difficulty inserting the shaft rather than forcing a fit. Passing these checks is only an unloaded mechanical result. Arm loads, servo torque, backlash and thermal duty remain untested.

## Geometry changes and remaining work

The preliminary platform height is about 142 mm above the board, not the earlier 100 mm shoulder-axis estimate. The final shoulder axis will be higher still; its exact height depends on the shoulder carrier. Recompute reach, dock approach and inverse kinematics with the actual shoulder-axis height before powered motion. No full-sheet reach or original workspace guarantee is carried into this taller prototype.

The servo plate's existing 52x32 mm mounting pattern fits the base's inner slots, allowing +/-6 mm X adjustment. This may not cover the actual output-axis offset: verify with the shaft before attaching any drive. Y adjustment and horn-height spacing may need a revised adapter after horn inspection. The manual assembly is independent of that pending motor alignment.

Source `rotating_base.scad` contains assembly and exploded inspection modes (`part="assembly"` or `part="exploded"`). Gray shaft, collars, washers and bearings are reference metal parts, never printable substitutes. Assembly view omits frame fasteners and servo hardware for clarity. Export only the individual print modes. No STEP or complete arm assembly is included in this stage.

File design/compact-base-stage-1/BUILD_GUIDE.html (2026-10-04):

Current update: You have built the turntable and reported smooth turning. At your request the threaded axle remains provisional for unloaded fitting. Continue with stage 2: motor mounting. The earlier axle stopping-point text below is historical; recheck support before attaching the arm.

CURRENT GUIDE • 28 SEPTEMBER 2026 • PARTS 01–09

# Build the robot’s turntable

One guide for the compact base you are printing. This replaces the earlier assembly instructions. It does not change any STL geometry.

Print / save as PDF

## 1. What you are building

You are building the unpowered rotating platform at the bottom of the robot. The arm, wrist, pen holder and electronics are later stages. The small gear and servo will eventually turn this platform, but they stay off during this assembly.

### Your current stopping point: the axle

You have a fully threaded M5 bolt. It can be a loose alignment aid for understanding the stack, if the parts slide on freely. It is not the approved bearing axle for a working base. Do not tighten this rehearsal assembly, attach the arm, or use a hand-turn result as proof of bearing fit.

The metal-sleeve idea mentioned earlier is not a designed replacement. No sleeve dimensions, replacement bearings or revised prints have been selected. Do not buy those parts on the basis of that suggestion.

### Do this now

1. Identify the printed parts using the table below.
2. Separate the hardware you already have from the missing items.
3. Use the diagram to understand the two stacks. A loose rehearsal is optional and only uses parts that fit without force.
4. Resolve the axle and missing fasteners before the final fastening and rotation test.

No new print version is required by this guide. Keep the small gear and all accepted fit-test parts.

Why there are two stacks: the central bolt, pedestal and small spacers stay still. The larger printed shell turns. Each bearing joins the two: its inner ring stays still and its outer ring turns with the shell.

## 2. Identify every printed part

Numbers below are STL file numbers, not assembly step numbers. You need ten pieces: one each of 01–09, plus a second 06. If you reuse your tested cap, printing one of each file supplies the rest.

File | Name | How to recognize it | Qty | Where it goes
01 | Base | Large square plate, 150 × 150 mm | 1 | Stays on the table; bolt enters from below.
02 | Pedestal | Stepped round post; narrow tip on one end | 1 | Stays fixed; narrow tip points UP.
03 | Lower rotor | Short square block, 9 mm tall | 1 | Holds the lower bearing.
04 | Large gear | Large toothed wheel | 1 | Turns with the platform.
05 | Upper rotor | Taller square block, 15.4 mm tall | 1 | Holds the upper bearing.
06 | Bearing cap | Thin square plate, 2 mm thick | 2 total | One below #03; one above #05. Reuse your tested cap.
07 | Top platform | Round plate, 80 mm diameter | 1 | The future arm will attach here.
08 | Inner spacer | Small hollow cylinder, 18 mm tall | 1 | Between the bearings, on the central bolt.
09 | Top spacer | Small hollow cylinder, 10 mm tall | 1 | Above the upper bearing, on the central bolt.

Set aside the older tall-base parts, the old single-bearing carrier, the servo plate and the small motor gear. The old carrier has an internal shoulder; the new rotor blocks have a through bore. They are different parts.

If still printing: keep your tested PLA process, 0.4 mm nozzle, 0.12 mm layers, 0.2 mm first layer, 100% scale. Use 4 walls, 5 top/bottom layers and 40% infill; use 100% for #02, #08 and #09. Print flat as exported without supports. Resin clearances have not been validated.

## 3. Hardware: what you have and what is missing

Item | Needed | Your current status / requirement
625-2RS bearings, 5 × 16 × 5 mm | 2 | Previously obtained/tested. Keep rubber seals in place.
M3 × 45 mm machine screws | 4 | Not in the pictured kit; its screws stop at 30 mm.
M3 regular nuts | 4 | Available in your M3 kit.
M3 flat washers | 8 | Available in your M3 kit; the stack assumes approximately 0.5 mm thickness. Use flat, not split lock washers.
M5 × 80 mm suitable axle bolt | 1 | Unresolved. Current design needs an 8.5 mm-diameter, 5 mm-high cylindrical socket head, smooth shank extending at least 55 mm below the head, and usable threads at 66.7–74.7 mm below the head. Both bearings must fit without visible rocking. The fully threaded bolt does not satisfy this.
M5 regular hex nuts | 2 | Availability unconfirmed; approximately 4 mm thick each.
Narrow metal M5 flat washers | 5 | Availability unconfirmed. Design size: 5.3 mm inner diameter × 9 mm outer diameter × 1 mm thick. Must touch inner metal rings without rubbing seals.

The M4 kit does not replace the M3 or M5 hardware. Do not enlarge the printed holes to fit it. Ordinary wide M5 washers are not automatically suitable next to bearings.

Tools: the correct Allen key for each screw and two wrenches fitting the M5 nuts. For practice without suitable fasteners, lay the pieces out rather than forcing a connection.

## 4. Where everything connects

Teal parts rotate together. Gray central parts remain fixed. Read the center-stack list from bottom to top. The side bolts are schematic projections of four corner bolts; only two are shown.

Numbered side cutaway of the compact turntable and inner stack order

Outer printed shell, bottom → top:
#06 → #03 → #04 → #05 → #06 → #07

The washers between the bearings are the five narrow M5 washers. The eight M3 washers belong only under the four side-screw heads and nuts. Do not mix the two groups.

## 5. Assembly, one step at a time

These steps describe the intended completed stack. If hardware is missing, use them as a layout reference. With the threaded bolt you currently have, stop before final tightening and testing.

1

### Lay out and identify the parts

Place #01–#09 on the table in numerical order. Put both #06 caps together. Keep the old bearing carrier separate: it has a recessed bearing pocket and is not a substitute for #03 or #05. Set the small motor gear, servo and servo plate aside.

Check: You have 10 printed pieces total, including two caps. No motor is connected.

2

### Insert the central bolt through #01

Turn the base over. Insert the M5 bolt through the center from the underside so its head sits inside the round recess. Turn the base upright while holding the bolt in place. The long bolt now points up.

Check: The base rests flat and the bolt head does not protrude underneath. A different head shape or size may not fit.

3

### Add #02 and the first narrow washer

Slide pedestal #02 over the bolt, broad end down on the base and narrow tip up. Place ONE narrow M5 washer on that tip. This is washer W1.

Check: The washer lies level on the tip. Do not substitute an M3 or M4 washer.

4

### Add the lower cap, lower rotor and lower bearing

Slide one #06 cap over the center bolt and pedestal tip. Place #03 on the cap. Align their four corner holes. Slide a 625 bearing down the axle into the top of #03 until its inner metal ring rests on W1. Guide it gently; do not hammer it or press on the rubber seal.

Check: The bearing is inside #03. The cap below stops its outer ring from escaping downward; W1 supports its inner ring.

5

### Build the spacer stack between bearings

On the lower bearing’s INNER metal ring, place W2, then spacer #08 (18 mm tall), then W3. All three slide over the central bolt.

Check: From the lower bearing upward: W2 → #08 → W3. The spacer does not sit on the outer ring or rubber seal.

6

### Add the large gear and upper rotor

Lower #04 over the central stack until it rests on #03. Add #05 on top of the gear. Rotate the loose printed pieces as needed so all four corner holes line up. Nothing is driven by the servo yet.

Check: Outer printed order so far, bottom upward: #06 → #03 → #04 → #05.

7

### Insert the upper bearing and close the shell

Slide the second 625 bearing down the central bolt into the top of #05 until its inner ring rests on W3. Add the second #06 cap, then platform #07. Align their four corner holes with the rest.

Check: There is one bearing near each end of the rotating shell, not two bearings together at one end.

8

### Connect the outer shell with FOUR M3 × 45 screws

For each of the four corner holes: put a flat M3 washer under the screw head, insert the screw downward through #07, upper #06, #05, #04, #03 and lower #06, then add a flat M3 washer and M3 nut underneath. Tighten gradually in alternating corners, just until seated.

Check: These four screws connect the rotating shell ONLY. They do not go through #02 or #01. Your 30 mm screws are too short; do not substitute them.

9

### Finish the central stack

Through the platform’s central opening, place W4 on the upper bearing’s inner ring, then #09 (10 mm), then W5. Add the first M5 nut above W5. For a loose rehearsal using your threaded bolt, STOP before tightening or testing.

Check: Central upper order: upper bearing → W4 → #09 → W5 → first M5 nut. These parts stay fixed while the platform turns around them.

10

### Secure and test — ONLY with a suitable axle

With both bearings on a verified smooth shank and the specified hardware fitted, seat the lower M5 nut gently against the stationary stack. Add the second M5 nut. Hold the lower nut with one wrench while locking the second against it, so the lower nut does not tighten farther. Stop if anything binds.

Check: Hold #01 and turn #07 gently by hand. It should turn smoothly without scraping, tight spots or visible rocking. Repeat after locking the nuts. This is an unloaded mechanical check, not permission to connect power.

## 6. If something does not fit

Symptom | What to check
Side screws do not reach the nuts | They must be M3 × 45, not the 30 mm screws in your kit. Check the two cap quantities and washer thickness. Do not omit washers or leave nuts partly engaged to make short screws fit.
A bearing will not enter the rotor | Confirm it is a 625 bearing and you have #03/#05, not an older carrier. Check loose print strands. Do not hammer the bearing or scale the entire model.
Center hole is blocked by a spacer | The narrow central spacers are intended to occupy that opening. The rotating cap/platform must clear their outside surfaces.
Platform becomes tight when nuts are tightened | Stop. Check washer contact, spacer order and whether the lower M5 nut moved while locking the second. Do not power the servo to overcome binding.
Platform rocks visibly | Check the axle-to-bearing fit, outer-bearing fit and loose side bolts. A threaded axle is not an accepted final fit. Do not hide the play with glue or tape.
Base will not sit flat | Check bolt-head size, the underside recess and any loose bridge strands. Do not force the base flat with board screws.
Top M5 nuts will not seat correctly | Verify the bolt length, threaded region and actual washer/spacer heights. Do not shorten spacers just to expose threads.

## 7. What happens after this stage

1. Resolve the axle and complete the unpowered turntable. It must rotate smoothly without visible rocking.
2. Finish the motor connection. Your horn/gear alignment and servo-case clearance checks passed, but horn attachment screws and installed gear height remain unresolved. Keep the original servo-center screw; do not replace it with a longer generic screw.
3. Set up and calibrate powered base travel. No wiring or powered-motion instructions are released in this guide.
4. Build and test the shoulder, elbow, wrist and pen system. Full-arm geometry, collision checks, load tests and shoulder heating remain to be completed.

For now: identify and lay out the parts. A working assembly still needs the appropriate axle, four M3 × 45 screws, and the specified M5 nuts/washers. Do not order a sleeve or different bearings yet.

This is a prototype build guide, not a claim that the complete robot is validated. Existing print dimensions are unchanged. Older tall-base instructions are superseded.

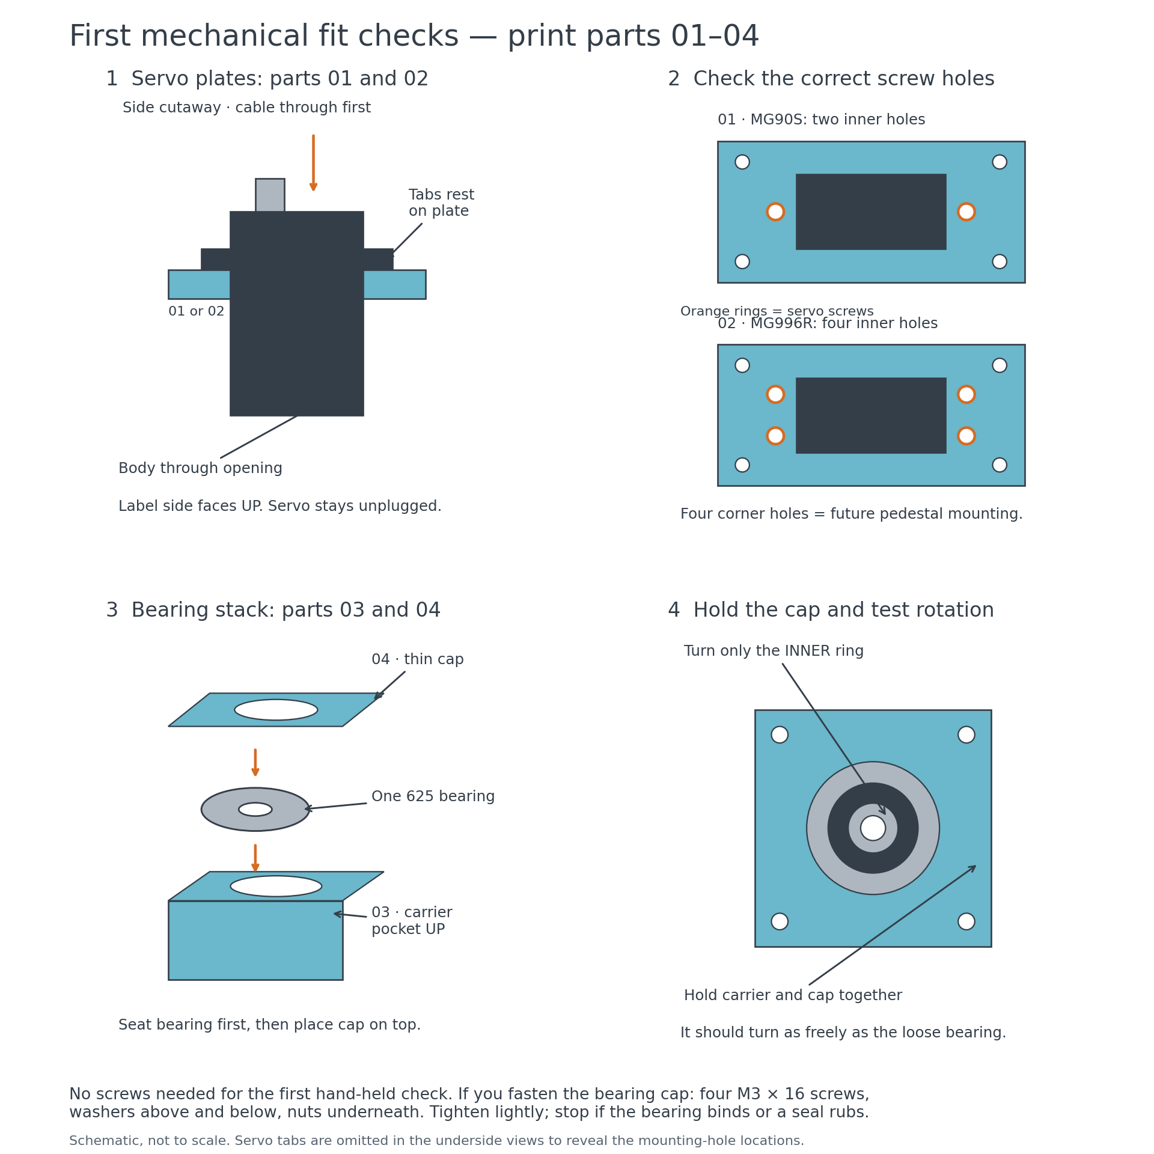
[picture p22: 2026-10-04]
design/mechanical-fit-v1/assembly_fit_guide.png

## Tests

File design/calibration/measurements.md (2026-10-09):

# Calibration measurements

Heights above the table, in inches (read from photos, about +/- 1/4 in).

## Pose A: s1100, e1500, w1450 (pen vertical)

| Point | in | mm |
|---|---|---|
| S shoulder nut | 5 | 127 |
| E elbow nut | 7 1/4 | 184 |
| W wrist screw | 4 5/8 | 117 |
| T pen tip | 2 | 51 |

Derived (L = 120 mm):

- Shoulder axis height: 127 mm (design 115)
- Upper arm: asin((184 - 127) / 120) = +28.5 deg at s1100 (design about +38)
- Forearm absolute: asin((117 - 184) / 120) = -33.8 deg, so the elbow is -62.3 deg at e1500 (design -90)
- Wrist at w1450: -90 - 28.5 + 62.3 = -56.2 deg (pen vertical)
- Wrist axis to pen tip, vertical: 67 mm (design 80)

## Pose B: s900, e1500, pen vertical at w1680

| Point | in | mm |
|---|---|---|
| S shoulder nut | 5 (same as A) | 127 |
| E elbow nut | 8 1/4 | 210 |
| W wrist screw | 7 5/16 | 186 |
| T pen tip | 4 5/8 (photos disagree, 4 1/2 to 5 1/4) | 117 |

Derived:

- Upper arm: asin((210 - 127) / 120) = +43.5 deg at s900
- Shoulder: 1100 -> 900 gave 15 deg, so about 13.9 us/deg. Level (0 deg) at about 1495 us, matching "1500 = level".
- Forearm absolute: -11.3 deg, so the elbow is -54.8 deg at e1500. Pose A gave -62.3, so use the average of about -58.5 (photo error about 3 deg).
- Wrist (pen vertical): -78.7 deg at w1680 vs -56.2 deg at w1450, so about 10.2 us/deg, and higher us = more negative.

## Pose C: s1100, e1300, pen vertical at w1680

No photos needed: the wrist acts as a level. w1680 means the wrist is at -78.7 deg, so the forearm is at -11.3 deg. With the shoulder at +28.5, the elbow is -39.8 deg at e1300.
Elbow: -58.5 at 1500 and -39.8 at 1300, so about 10.7 us/deg. Lower us = forearm up.

## Result (angles in degrees; positive = up; elbow and wrist relative to the previous link)

    shoulder_us = 1495 - 13.9 * shoulder
    elbow_us    = 1500 - 10.7 * (elbow + 58.5)
    wrist_us    = 1450 - 10.2 * (wrist + 56.2)
    shoulder axis 127 mm above the table, pen tip 67 mm below the wrist axis, offset 25 mm forward (design, not measured)

Drawing patch at z = 0:

| r mm | s us | e us | w us |
|---|---|---|---|
| 135 | 1079 | 2127 | 906 |
| 150 | 1091 | 2045 | 975 |
| 165 | 1114 | 1957 | 1042 |
| 180 | 1147 | 1862 | 1108 |
| 197 | 1198 | 1743 | 1184 |

The near half needs elbow > 1900 and wrist < 950, so the arm_test limits were widened to elbow 2200 and wrist 880, pending a clearance check.

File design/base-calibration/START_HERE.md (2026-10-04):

# Stage 4: base calibration and repeatability

You'll measure three things before any arm parts go on the base:

1. **Scale:** how far the platform turns per microsecond of servo pulse.
2. **Travel:** whether the base reaches the planned ±35° without straining.
3. **Repeatability:** whether it returns to the same spot every time. This is the "base repeatability" test from the original spec.

A pen held 120 mm from the axis hovers over a ruler. At that radius, 1° of turn moves the tip about 2.1 mm.

See `setup_preview.png` for the complete setup and `pointer_mounting_diagram.png` for how the pointer bolts on.

## Print

`calibration_pointer.stl`, one copy. PLA, your usual 0.12 mm profile, 4 walls, 30% infill, 100% scale, flat as exported, no supports. It's 170 × 42 × 24 mm and fits the A1 mini bed straight.

## Hardware (all from your kits)

- 4 × M3 × 16 screws (× 20 also works), 4 × M3 nuts, 4 × M3 washers: pointer to platform
- 1 × M3 × 16 screw + 1 × M3 nut: pen set screw
- Any pen or pencil 8–15 mm thick (a felt-tip is fine)
- A ruler with millimeter marks, plus tape

## Set up

1. **Bolt the pointer to the platform.** It sits flat on the platform top. The four small holes line up with the platform's four outer holes (the ones not used by the turntable bolts). The large holes clear the turntable bolt heads and the center nuts. Put the screws down from the top, with a washer and nut underneath the platform. You can reach under from the side, above the big gear.
2. **Fit the pen.** Drop the M3 nut into the slot on the sleeve's outer block, then thread the M3 × 16 screw in from outside. Slide the pen down through the sleeve, tip pointing down. Set the tip about **1 mm above the table** and tighten the screw just enough to hold it.
3. **Keep the base from moving.** Tape or clamp the base to the table. If it slides, every reading is wrong.
4. **Tape the ruler to the table under the pen tip.** The ruler should run crosswise to the pointer, so the tip travels along it.
5. Clear the table in a circle about 25 cm around the base. The pen swings along an arc during the travel test.

## Upload the new sketch

Open `base_calibration/base_calibration.ino` and upload it the same way as before (Arduino Nano, Old Bootloader, COM3). Close the Serial Monitor first, or the upload can't open the port. Then reopen Serial Monitor at 115200 with Newline.

This sketch allows 600–2400 µs and adds an `r` command. It still moves in slow steps.

## Test A: scale and direction

1. Plug in the adapter. Type `c`. Note the ruler reading under the tip.
2. Type `1700`. Note the new reading. The difference is **d** (mm).
3. From above, note the direction the platform turned for `1700`: **clockwise or counterclockwise**.
4. Type `1300`, then `c`. The tip should land about the same distance on the other side.

## Test B: travel to ±35°

Find your **d** in this table and use the two pulse values on that row.

| d (mm, 1500→1700) | Platform turned (°) | µs per degree | −35° pulse | +35° pulse |
|---:|---:|---:|---:|---:|
| 16 | 7.6 | 26.3 | 578 | 2422 |
| 18 | 8.5 | 23.4 | 679 | 2321 |
| 20 | 9.5 | 21.1 | 760 | 2240 |
| 22 | 10.4 | 19.3 | 826 | 2174 |
| 24 | 11.3 | 17.7 | 881 | 2119 |
| 26 | 12.2 | 16.4 | 927 | 2073 |
| 28 | 13.1 | 15.2 | 967 | 2033 |
| 30 | 14.0 | 14.2 | 1001 | 1999 |

Round d to the nearest row. If d is **below 17 mm**, the servo can't reach ±35° inside 600–2400 µs. Do only steps 1–2 below using 700 and 2300, then report.

1. Walk out in 100 µs steps toward the **+35° pulse** (for example `1800`, `1900`, `2000`, and so on), then type that pulse itself. Watch and listen at each step.
2. Type `c`, then walk out the same way to the **−35° pulse**.
3. Type `c` to return to center.

**Pass:** it moves at every step, reaches both pulses smoothly, and holds without loud buzzing. No gear clicks or skipped teeth.
**Fail:** the platform stops moving while the pulse keeps changing (the servo has hit its internal limit), buzzing or straining, or gear skipping. Type the last good pulse, then `o`, and report where it failed. Don't keep pushing past the point where the platform stops moving.

## Test C: repeatability

1. Type `c` and wait a few seconds.
2. Type `r`. The base swings out and back to center 10 times from the PLUS side, then 10 times from the MINUS side. It pauses 4 seconds at center each time and prints a line like `PLUS side #3 -> read the ruler now`.
3. Write down the ruler reading at every pause, to the nearest 0.5 mm. It's easier to film the tip with your phone and read the video afterward.
4. Press Enter at any time to stop.

**Pass:** all 20 readings fall within **1.2 mm** of each other, and the PLUS average and MINUS average differ by no more than 1.2 mm. At 120 mm, this is the same angle as the spec's 2 mm at 200 mm, about 0.6°.
**If it fails:** don't worry yet. Report the numbers. A consistent PLUS-versus-MINUS gap is gear and servo backlash. Random scatter points to something loose, such as the horn screws, the gear-to-horn screws, the motor-plate nuts, or the axle.

## Report back

- **d** and direction (clockwise or counterclockwise for 1700)
- Test B: pass, or where it stopped
- Test C: the 20 readings (or a video of the run)

## Why this matters

These numbers turn "pulse width" into real base angles for the software. They confirm the dock direction (about −27°) is reachable, and they tell us whether base backlash is small enough for 60 mm drawings before we spend filament on the shoulder.

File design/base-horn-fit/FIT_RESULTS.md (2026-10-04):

# Accepted physical checks

User provided IMG_9222.png and confirmed flush seating and opposite hole alignment, then confirmed MG90S case clearance and center-screw access. Shaft compatibility was previously confirmed. Keep this gear; no reprint required on this evidence.

Horn attachment screws and loaded drive performance are NOT validated. User owns only supplied servo screws. Next build is ../compact-base-stage-1, a passive turntable with motor detached.

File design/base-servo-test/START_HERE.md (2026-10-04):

# Stage 3: first powered test — center the base servo

Goal: command the base MG90S to its center position with the gears **out of mesh**, then re-mesh the gears so the platform's center matches the servo's center.

This is one servo, no arm, no load. Nothing else is powered.

## What you need

- Arduino Nano + its USB cable
- ONE HiLetgo PCA9685 board (keep the second as a spare)
- Basicvolt 5 V 3 A adapter, with the **plain barrel plug** on the cord (no tip adapter)
- The **female** end of the 18 AWG barrel pigtail pair
- 4 female-to-female jumpers (ELEGOO kit)
- Multimeter
- Small flat screwdriver for the green screw terminal
- Arduino IDE (already installed on your PC)

## 1. Check the power adapter first (nothing else connected)

1. Plug the adapter's barrel into the female pigtail.
2. Plug the adapter into the wall.
3. Multimeter on DC volts: red probe on the pigtail's **red** wire, black probe on its **black** wire.
4. **Pass:** +4.9 to +5.3 V. **Fail:** negative reading (polarity reversed), or above 5.5 V. Stop and report it.
5. Unplug the adapter from the wall.

## 2. Wire it (adapter unplugged)

Follow `wiring_diagram.png`.

| From | To |
|---|---|
| Nano **GND** | PCA9685 header **GND** |
| Nano **5V** (not VIN) | PCA9685 header **VCC** |
| Nano **A4** | PCA9685 header **SDA** |
| Nano **A5** | PCA9685 header **SCL** |
| Pigtail **red** | green terminal **V+** |
| Pigtail **black** | green terminal **GND** |
| Servo plug | Channel **0**: brown on GND row (board edge), orange on PWM row |

Leave the header's **OE** and **V+** pins empty. Tug each screw-terminal wire gently to confirm it's clamped on bare copper, not insulation.

## 3. Upload the test sketch (adapter still unplugged)

1. Open `base_servo_test/base_servo_test.ino` in Arduino IDE. No extra libraries are needed.
2. **Tools → Board → Arduino Nano.**
3. **Tools → Processor:** try **ATmega328P (Old Bootloader)** first. Most clone Nanos need it. If the upload fails, switch to **ATmega328P**.
4. **Tools → Port:** pick the COM port that appears when the Nano is plugged in. If no port appears, your Nano probably uses a CH340 USB chip and needs its Windows driver. Tell me and I'll walk you through it.
5. Upload, then open **Serial Monitor** at **115200 baud** with **Newline** line ending.
6. **Pass:** it prints `PCA9685 found`. **Fail:** `NOT found` means one of the four jumpers is wrong or loose.

At this point the servo gets no signal, so it stays limp. That's intended.

## 4. Center the servo

1. Confirm the small gear is **not touching** the large gear.
2. Plug the adapter into the wall. The driver's LED lights. The servo should stay still.
3. Type `c` and press Enter. The servo turns once to center (1500 µs) and holds.
4. Try `+` and `-` a few times. It should nudge a small amount each time and hold firmly.
5. Type `1300`, then `1700`. It should move smoothly to each position and stop.
6. Type `c` to return to center. **Leave it powered at center.**

**Pass:** smooth moves, holds position, no buzzing louder than a faint hum, servo body stays cool to the touch after 2 minutes.
**Fail:** jitter, continuous buzzing, the Nano resetting (the `PCA9685 found` message reappears), or a hot servo. Type `o` to release the servo, unplug the adapter, and report which symptom you saw.

## 5. Re-mesh the gears at center

1. With the servo **holding center**, turn the turntable by hand so the platform faces the middle of where the sticky note will be. This makes center equal "pointing at the drawing area".
2. Loosen the four motor-plate nuts slightly and slide the plate toward the large gear until the teeth mesh. Don't let the small gear rotate. If tooth tips collide, nudge the **platform** a few degrees and retry.
3. Aim for barely-there play: rocking the platform should give a tiny click, not grinding and not tightness. A strip of printer paper between the teeth while you tighten, then pulled out, gives about the right gap.
4. Tighten the four nuts evenly.
5. Type `o` to release the servo, then unplug the adapter.

## 6. First geared motion check

1. Plug the adapter back in. Type `c`. The platform should hold where you set it, or move only slightly.
2. Type `1400`, then `1600`, then `c`. The platform should swing a little each way and return.

**Pass:** smooth, no skipped teeth, no grinding, no tight spot, and the plate doesn't shift.
**Fail:** clicking or skipping teeth, stalling, or the servo straining. Type `o`, unplug, and report it.

Stay within 1300–1700 µs for now. Full travel limits come after we confirm how far the platform can swing without hitting anything.

## Report back

- Voltage reading from step 1
- Did `PCA9685 found` print?
- Steps 4 and 6: pass, or which symptom?
- A short video of step 6 if you can.

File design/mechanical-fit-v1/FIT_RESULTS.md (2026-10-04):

# Mechanical fit V1 — results, 2026-09-25

User reported "everything good" in response to the requested checks of parts 01–04: both servos sit flat with aligned holes, and the bearing turns freely with the cap held in place.

## Accepted physical interfaces

- 01 MG90S mounting plate: body fit and mounting-hole alignment accepted, selected A = 27 mm.
- 02 MG996R mounting plate: body fit and four-hole alignment accepted, selected A = 49 mm and B = 10 mm.
- 03 bearing carrier and 04 cap: bearing seating and hand-held cap rotation check accepted; 16.3 mm pocket diameter retained.

The user's confirmation supports the requested hand-held fit checks. It does not establish screw sizes used, screw-tightened bearing rotation, servo-powered operation, shaft alignment, structural strength, or shoulder load/thermal performance. No result is inferred for the optional base or spacer assemblies (parts 05–07).

## Next design stage

Use these accepted plate and bearing-seat interfaces to develop the bearing-supported base rotation assembly and horn coupling, followed by shoulder/elbow carriers and links. Preserve removable servo attachment and independent structural support. Actual horn attachment geometry and output-axis location remain to be resolved before a complete driven joint can be released. Retain the planned shoulder load test, especially with wrist rotation installed.

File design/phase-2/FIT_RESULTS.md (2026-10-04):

# Fit results — 2026-09-24

User-reported physical test results, with slicer settings transcribed from the supplied screenshot.

| Test | Reported result | Design interpretation |
|---|---|---|
| MG90S body | +0.6 best | Add 0.6 mm total to nominal length and width: 0.3 mm per side |
| MG996R body | +0.6 best | Add 0.6 mm total to nominal length and width: 0.3 mm per side |
| 625 bearing | 16.3 best | Use 16.3 mm nominal CAD bore as starting point; retain bearing with caps |
| Slider | User selected 0.3 after follow-up | Use 0.3 mm per side; final spring-loaded guide still needs testing |
| Sticky-note holder | Fits good | Keep current nominal holder geometry; actual note dimensions not measured/reported |

## Slicer settings shown

- Printer profile: Bambu Lab A1 mini.
- Nozzle: 0.4 mm, standard flow.
- Filament profile: Generic PLA (actual filament brand not supplied).
- Layer height: 0.12 mm; initial layer: 0.20 mm.
- Seam: aligned.

These fit allowances apply to this tested printing setup. Do not assume identical results at 0.2 mm layer height, with PETG, or with resin. Fit-critical pockets should retain the tested settings or be rechecked after a process change. Design future parts within the A1 mini build envelope, rather than the larger bed originally assumed.

## Derived CAD openings

- MG90S reference body opening: 23.4 x 12.8 mm.
- MG996R reference body opening: 41.3 x 20.3 mm.
- Bearing pocket diameter: 16.3 mm. Depth, axial clearance and retention are not established by the through-hole coupon.
- Slider side clearance: 0.3 mm per side, 0.6 mm total additional channel width.

These tests establish body-fit clearances and the selected mounting patterns below, not full servo mounting geometry. Horn offsets, wire exits and supported axle geometry still require verification. The slider coupon does not verify an enclosed guide, friction under spring load, or vertical clearance.

Follow-up: user selected the 0.3 mm slider channel.

## Mounting-template results

User reported: "m1a27 and s2a49b10".

- MG90S: M1, A = 27 mm center-to-center between end mounting holes.
- MG996R: S2, A = 49 mm lengthwise and B = 10 mm across each end tab.
- Carry these nominal pattern dimensions into bracket CAD alongside the confirmed body openings. This is a visual template selection, not a precision caliper measurement. M1 is the smallest tested MG90S spacing; if a later bracket shows systematic misalignment, revisit that boundary rather than force assembly.
- The template's small reference-hole diameters are not final mounting-screw clearances. Final holes must match actual fasteners and tab geometry.
- Next design step: removable servo brackets and supported joints, with assembly fit verification. No additional measurement tracing is needed for these selected patterns.

## Mechanical plate and bearing retention follow-up — 2026-09-25

The user accepted the parts 01–04 checks with "everything good": both servo plates sit flat with aligned holes, and the bearing turns freely with the cap held in place. See `../mechanical-fit-v1/FIT_RESULTS.md` for scope. This confirms hand-held fit, not powered or load-tested operation. Optional base and spacer parts have no reported fit result yet.

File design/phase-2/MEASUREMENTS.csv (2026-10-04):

component | measurement | unit | value | notes
MG90S | body_length | mm |  | Exclude mounting ears
MG90S | body_width | mm |  | Exclude mounting ears
MG90S | depth_below_ears | mm
MG90S | total_height_to_shaft_top | mm
MG90S | ear_span | mm
MG90S | ear_thickness | mm
MG90S | hole_spacing_length | mm |  | Center to center
MG90S | hole_spacing_width | mm |  | If applicable
MG90S | mount_hole_diameter | mm
MG90S | shaft_axis_from_end | mm |  | Name reference face
MG90S | shaft_axis_from_side | mm |  | Name reference face
MG90S | horn_dimensions_and_holes | text |  | Record supplied horn used
MG90S | wire_exit_clearance | mm
MG996R | body_length | mm |  | Measure actual purchased servo
MG996R | body_width | mm
MG996R | depth_below_ears | mm
MG996R | total_height_to_shaft_top | mm
MG996R | ear_span | mm
MG996R | ear_thickness | mm
MG996R | hole_spacing_length | mm
MG996R | hole_spacing_width | mm
MG996R | mount_hole_diameter | mm
MG996R | shaft_axis_from_end | mm
MG996R | shaft_axis_from_side | mm
MG996R | horn_dimensions_and_holes | text
pen | diameter | mm
pen | total_length | mm
pen | mass | g
pen | grip_to_tip | mm
note | width | mm
note | height | mm
note | single_sheet_thickness | mm |  | Optional if difficult to measure
webcam | mass | g
webcam | mount_envelope | text
resin | brand_and_type | text

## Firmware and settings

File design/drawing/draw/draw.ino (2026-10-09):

// Scribbot drawing program: Arduino Nano + PCA9685.
// Channel 0 = base, 1 = shoulder, 2 = elbow, 3 = wrist.
// Serial Monitor at 115200 baud, "Newline".
//
// Positions are in mm from the base axis: x = straight out, y = sideways, z = pen tip height.
// The pen always points straight down.
//
// Commands:
//   h       hover 25 mm above the middle of the note (do this first)
//   d  u    pen down / up 1 mm (D / U = 5 mm)
//   t       "the pen is touching the paper right now": saves this height
//   q       draw a 40 mm square          (q, c, s and w need t first)
//   c       draw a 40 mm circle
//   s       draw a star
//   wHI     write text: letters, numbers and spaces, up to 8 characters
//   m       text comes out mirrored? send m once to flip it
//   v       text comes out upside down? send v once to turn it
//   l  r    turn the whole drawing 1 degree left / right
//   ?       show position and pulses
//   o       all joints off (the arm DROPS: support it first)

#include <Wire.h>
#include <math.h>
#include <avr/pgmspace.h>

const uint8_t PCA_ADDR = 0x40;

// Geometry (mm), from calibration.
const float L1 = 120, L2 = 120;   // upper arm, forearm
const float SH_H = 127;           // shoulder axis above the table
const float PEN_D = 67;           // wrist axis to pen tip, straight down
const float PEN_E = 25;           // pen tip ahead of the wrist axis

// Note center and drawing sizes.
const float NOTE_X = 166, NOTE_Y = 0;
const float SIZE = 40;            // square side, circle diameter
const float TEXT_W = 50;          // text never wider than this
const float TEXT_H = 14;          // or taller than this
const float HOVER = 25;           // hover height above the paper
const float LIFT = 6;             // pen-up height while drawing
const float PRESS = 2;            // go this far below the paper (the holder slides up)

const int MIN_US[4] = {720, 700, 950, 880};
const int MAX_US[4] = {2280, 1550, 2200, 1700};

float px, py, pz;                 // current pen position
float paperZ = 0;                 // saved by t
bool paperSet = false;
bool armOn = false;
float baseTrim = 0;               // degrees, from l / r
bool mirrorText = false;          // m
bool flipText = false;            // v
int us[4];

// Stroke font on a 4 x 6 grid. Each point is two digits (x, y), y up.
// A space lifts the pen.
const char F_A[] PROGMEM = "0004264440 0343";
const char F_B[] PROGMEM = "00063645443303 3342413000";
const char F_C[] PROGMEM = "4536160501103041";
const char F_D[] PROGMEM = "00062644422000";
const char F_E[] PROGMEM = "40000646 0333";
const char F_F[] PROGMEM = "000646 0333";
const char F_G[] PROGMEM = "45361605011030414323";
const char F_H[] PROGMEM = "0006 4046 0343";
const char F_I[] PROGMEM = "1030 2026 1636";
const char F_J[] PROGMEM = "4641301001";
const char F_K[] PROGMEM = "0006 4603 1440";
const char F_L[] PROGMEM = "060040";
const char F_M[] PROGMEM = "0006234640";
const char F_N[] PROGMEM = "00064046";
const char F_O[] PROGMEM = "100105163645413010";
const char F_P[] PROGMEM = "00063645443303";
const char F_Q[] PROGMEM = "100105163645413010 2240";
const char F_R[] PROGMEM = "00063645443303 3340";
const char F_S[] PROGMEM = "453616050413334241301001";
const char F_T[] PROGMEM = "0646 2620";
const char F_U[] PROGMEM = "060110304146";
const char F_V[] PROGMEM = "062046";
const char F_W[] PROGMEM = "0600234046";
const char F_X[] PROGMEM = "0046 0640";
const char F_Y[] PROGMEM = "062346 2320";
const char F_Z[] PROGMEM = "06460040";
const char F_0[] PROGMEM = "100105163645413010 0541";
const char F_1[] PROGMEM = "152620 1030";
const char F_2[] PROGMEM = "05163645440040";
const char F_3[] PROGMEM = "05163645443313 334241301001";
const char F_4[] PROGMEM = "30360242";
const char F_5[] PROGMEM = "460603334241301001";
const char F_6[] PROGMEM = "4536160501103041423303";
const char F_7[] PROGMEM = "064620";
const char F_8[] PROGMEM = "13040516364544331302011030414233";
const char F_9[] PROGMEM = "4313040516364541301001";
const char* const LETTERS[26] PROGMEM = {F_A, F_B, F_C, F_D, F_E, F_F, F_G, F_H, F_I, F_J, F_K, F_L, F_M,
                                         F_N, F_O, F_P, F_Q, F_R, F_S, F_T, F_U, F_V, F_W, F_X, F_Y, F_Z};
const char* const DIGITS[10] PROGMEM = {F_0, F_1, F_2, F_3, F_4, F_5, F_6, F_7, F_8, F_9};

void writeReg(uint8_t reg, uint8_t value) {
  Wire.beginTransmission(PCA_ADDR);
  Wire.write(reg);
  Wire.write(value);
  Wire.endTransmission();
}

void setChannelTicks(uint8_t ch, uint16_t on, uint16_t off) {
  Wire.beginTransmission(PCA_ADDR);
  Wire.write(0x06 + 4 * ch);
  Wire.write(on & 0xFF);
  Wire.write(on >> 8);
  Wire.write(off & 0xFF);
  Wire.write(off >> 8);
  Wire.endTransmission();
}

void writeUs(uint8_t ch, int u) {
  setChannelTicks(ch, 0, (uint32_t)u * 4096UL / 20000UL);
}

void allOff() {
  for (uint8_t ch = 0; ch < 4; ch++) setChannelTicks(ch, 0, 0x1000);
  armOn = false;
}

// Pen position -> pulses. Returns false if out of reach or past a joint limit.
bool solve(float x, float y, float z, int out[4]) {
  float r = sqrt(x * x + y * y);
  float base = atan2(y, x) * 180 / M_PI + baseTrim;
  float rw = r - PEN_E, zw = z + PEN_D - SH_H;
  float dd = sqrt(rw * rw + zw * zw);
  float c = (dd * dd - L1 * L1 - L2 * L2) / (2 * L1 * L2);
  if (c < -1 || c > 1) return false;
  float elbow = -acos(c) * 180 / M_PI;
  float shoulder = (atan2(zw, rw) + acos(dd / (L1 + L2))) * 180 / M_PI;
  float wrist = -90 - shoulder - elbow;

  out[0] = 1500 + 22.2 * base;
  out[1] = 1495 - 13.9 * shoulder;
  out[2] = 1500 - 10.7 * (elbow + 58.5);
  out[3] = 1450 - 10.2 * (wrist + 56.2);
  for (uint8_t j = 0; j < 4; j++) if (out[j] < MIN_US[j] || out[j] > MAX_US[j]) return false;
  return true;
}

void report() {
  Serial.print(F("pen x=")); Serial.print(px, 1);
  Serial.print(F(" y=")); Serial.print(py, 1);
  Serial.print(F(" z=")); Serial.print(pz, 1);
  if (paperSet) { Serial.print(F("  (paper z=")); Serial.print(paperZ, 1); Serial.print(')'); }
  Serial.print(F("   b s e w = "));
  for (uint8_t j = 0; j < 4; j++) { Serial.print(us[j]); Serial.print(' '); }
  Serial.println();
}

// Straight line to (x, y, z) in 1 mm steps.
bool lineTo(float x, float y, float z) {
  float dx = x - px, dy = y - py, dz = z - pz;
  int steps = max(1, (int)ceil(sqrt(dx * dx + dy * dy + dz * dz)));
  int t[4];
  for (int i = 1; i <= steps; i++) {
    float f = (float)i / steps;
    if (!solve(px + dx * f, py + dy * f, pz + dz * f, t)) {
      Serial.println(F("Out of reach. Stopped."));
      return false;
    }
    for (uint8_t j = 0; j < 4; j++) { us[j] = t[j]; writeUs(j, t[j]); }
    delay(20);
  }
  px = x; py = y; pz = z;
  return true;
}

// Pen up, travel to (x, y), pen down.
bool penTo(float x, float y) {
  float up = paperZ + LIFT;
  return lineTo(px, py, up) && lineTo(x, y, up) && lineTo(x, y, paperZ - PRESS);
}

// Draw (pen already down) to (x, y).
bool drawTo(float x, float y) {
  return lineTo(x, y, paperZ - PRESS);
}

void finish(const __FlashStringHelper* msg) {
  lineTo(px, py, paperZ + LIFT);
  lineTo(NOTE_X, NOTE_Y, paperZ + LIFT);
  Serial.println(msg);
}

// First move from off: one joint at a time, shoulder first so the arm lifts.
void powerOn(float x, float y, float z) {
  int t[4];
  if (!solve(x, y, z, t)) { Serial.println(F("Hover point out of reach.")); return; }
  const uint8_t order[4] = {1, 2, 3, 0};
  for (uint8_t k = 0; k < 4; k++) {
    uint8_t j = order[k];
    us[j] = t[j];
    writeUs(j, t[j]);
    delay(700);
  }
  px = x; py = y; pz = z;
  armOn = true;
}

void square() {
  float h = SIZE / 2;
  float cx[5] = {NOTE_X - h, NOTE_X + h, NOTE_X + h, NOTE_X - h, NOTE_X - h};
  float cy[5] = {NOTE_Y - h, NOTE_Y - h, NOTE_Y + h, NOTE_Y + h, NOTE_Y - h};
  if (!penTo(cx[0], cy[0])) return;
  for (uint8_t i = 1; i < 5; i++) if (!drawTo(cx[i], cy[i])) return;
  finish(F("Square done."));
}

void circle() {
  float rad = SIZE / 2;
  if (!penTo(NOTE_X + rad, NOTE_Y)) return;
  for (int i = 1; i <= 72; i++) {
    float a = i * 2 * M_PI / 72;
    if (!drawTo(NOTE_X + rad * cos(a), NOTE_Y + rad * sin(a))) return;
  }
  finish(F("Circle done."));
}

void star() {
  float rad = SIZE / 2 + 2;
  for (int i = 0; i <= 5; i++) {
    float a = (i * 2 % 5) * 2 * M_PI / 5;   // every second point: 0, 2, 4, 1, 3, 0
    float x = NOTE_X - rad * cos(a), y = NOTE_Y + rad * sin(a);
    if (i == 0 ? !penTo(x, y) : !drawTo(x, y)) return;
  }
  finish(F("Star done."));
}

// Text. The reader's "up" on the paper points toward the base (-x), "right" is +y.
// m and v flip these if the test comes out wrong.
void textPoint(float gx, float gy, float u, float left, float bottom, float& x, float& y) {
  float right = left + gx * u, up = bottom + gy * u;   // mm in the reader's frame, centered on the note
  if (flipText) { right = -right; up = -up; }
  if (mirrorText) right = -right;
  x = NOTE_X - up;
  y = NOTE_Y + right;
}

void writeText(String s) {
  s.toUpperCase();
  int n = s.length();
  if (n == 0 || n > 8) { Serial.println(F("Use 1 to 8 characters, like wHI")); return; }
  // Each character is 4 units wide plus 2 units of gap; 6 units tall.
  float u = min(TEXT_H / 6, TEXT_W / (6 * n - 2));
  float left = -(6 * n - 2) * u / 2, bottom = -3 * u;
  char buf[40];
  for (int k = 0; k < n; k++) {
    char ch = s.charAt(k);
    const char* p = nullptr;
    if (ch >= 'A' && ch <= 'Z') p = (const char*)pgm_read_ptr(&LETTERS[ch - 'A']);
    else if (ch >= '0' && ch <= '9') p = (const char*)pgm_read_ptr(&DIGITS[ch - '0']);
    if (p) {
      strncpy_P(buf, p, sizeof(buf) - 1);
      buf[sizeof(buf) - 1] = 0;
      bool penDown = false;
      for (int i = 0; buf[i]; ) {
        if (buf[i] == ' ') { penDown = false; i++; continue; }
        float x, y;
        textPoint(buf[i] - '0', buf[i + 1] - '0', u, left + k * 6 * u, bottom, x, y);
        if (!(penDown ? drawTo(x, y) : penTo(x, y))) return;
        penDown = true;
        i += 2;
      }
    }
  }
  finish(F("Text done."));
}

void setup() {
  Serial.begin(115200);
  Wire.begin();
  delay(200);
  Wire.beginTransmission(PCA_ADDR);
  if (Wire.endTransmission() != 0) {
    Serial.println(F("PCA9685 NOT found at 0x40. Check VCC, GND, SDA->A4, SCL->A5."));
    while (true) {}
  }
  writeReg(0x00, 0x10);
  writeReg(0xFE, 121);
  writeReg(0x00, 0x20);
  delay(1);
  writeReg(0x00, 0xA0);
  allOff();
  Serial.println(F("SCRIBBOT DRAW. Start with h (hover). Then d / u, t, then q c s or wHI."));
}

void loop() {
  if (!Serial.available()) return;
  String cmd = Serial.readStringUntil('\n');
  cmd.trim();
  if (cmd.length() == 0) return;
  char c = cmd.charAt(0);

  if (c == 'o') { allOff(); Serial.println(F("ALL joints OFF.")); return; }
  if (c == 'm') { mirrorText = !mirrorText; Serial.println(mirrorText ? F("Text mirror ON.") : F("Text mirror OFF.")); return; }
  if (c == 'v') { flipText = !flipText; Serial.println(flipText ? F("Text turned 180.") : F("Text normal.")); return; }
  if (c == 'h') {
    float z = (paperSet ? paperZ : 0) + HOVER;
    if (!armOn) powerOn(NOTE_X, NOTE_Y, z);
    else lineTo(NOTE_X, NOTE_Y, z);
    report();
    return;
  }
  if (!armOn) { Serial.println(F("Arm is off. Send h first.")); return; }
  if ((c == 'q' || c == 'c' || c == 's' || c == 'w') && !paperSet) { Serial.println(F("Do t first.")); return; }

  switch (c) {
    case 'd': lineTo(px, py, pz - 1); break;
    case 'D': lineTo(px, py, pz - 5); break;
    case 'u': lineTo(px, py, pz + 1); break;
    case 'U': lineTo(px, py, pz + 5); break;
    case 't':
      paperZ = pz; paperSet = true;
      Serial.println(F("Paper height saved."));
      lineTo(px, py, pz + LIFT);
      break;
    case 'q': square(); break;
    case 'c': circle(); break;
    case 's': star(); break;
    case 'w': writeText(cmd.substring(1)); break;
    case 'l': case 'r': {
      float old = baseTrim;
      baseTrim += (c == 'l') ? -1 : 1;
      if (!lineTo(px, py, pz)) baseTrim = old;
      break;
    }
    case '?': break;
    default: Serial.println(F("Commands: h d u D U t q c s wTEXT m v l r ? o")); return;
  }
  report();
}

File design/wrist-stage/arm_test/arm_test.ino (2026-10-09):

// Arm joint test: Arduino Nano + PCA9685.
// Channel 0 = base (b), channel 1 = shoulder (s), channel 2 = elbow (e), channel 3 = wrist (w).
// No extra libraries needed. Serial Monitor at 115200 baud, "Newline".
//
// Commands (joint letter first):
//   e1500    move the elbow to 1500 us      (also b1500, s1500, w1500)
//   e+  e-   nudge the elbow 10 us          (also b+, s-, w+ ...)
//   eo       elbow off / limp               (also bo, so, wo)
//   o        ALL joints off (the arm DROPS: support it first)
//   ?        show every joint
//
// All outputs stay OFF at startup until you command a joint.
// Every move steps 10 us every 25 ms, so joints move slowly.

#include <Wire.h>

const uint8_t PCA_ADDR = 0x40;
const uint8_t JOINTS = 4;
const char JOINT_KEY[JOINTS] = {'b', 's', 'e', 'w'};
const char* const JOINT_NAME[JOINTS] = {"base", "shoulder", "elbow", "wrist"};
const int MIN_US[JOINTS] = {720, 700, 950, 880};   // wrist: LOWER = pen turns toward vertical. Drawing needs down to ~905
const int MAX_US[JOINTS] = {2280, 1550, 2200, 1700};  // shoulder: 1500 = level, lower = up. elbow: higher = forearm folds down; drawing needs up to ~2130
const int NUDGE_US = 10;

int currentUs[JOINTS] = {-1, -1, -1, -1};  // -1 = output off

void writeReg(uint8_t reg, uint8_t value) {
  Wire.beginTransmission(PCA_ADDR);
  Wire.write(reg);
  Wire.write(value);
  Wire.endTransmission();
}

void setChannelTicks(uint8_t ch, uint16_t on, uint16_t off) {
  Wire.beginTransmission(PCA_ADDR);
  Wire.write(0x06 + 4 * ch);
  Wire.write(on & 0xFF);
  Wire.write(on >> 8);
  Wire.write(off & 0xFF);
  Wire.write(off >> 8);
  Wire.endTransmission();
}

void jointOff(uint8_t j) {
  setChannelTicks(j, 0, 0x1000);  // full-off bit
  currentUs[j] = -1;
}

void writeUs(uint8_t j, int us) {
  // 50 Hz frame = 20000 us split into 4096 ticks.
  uint16_t ticks = (uint32_t)us * 4096UL / 20000UL;
  setChannelTicks(j, 0, ticks);
  currentUs[j] = us;
}

void report(uint8_t j) {
  Serial.print(JOINT_NAME[j]);
  Serial.print(F(" = "));
  if (currentUs[j] < 0) Serial.println(F("OFF"));
  else { Serial.print(currentUs[j]); Serial.println(F(" us")); }
}

void moveTo(uint8_t j, int target) {
  target = constrain(target, MIN_US[j], MAX_US[j]);
  if (currentUs[j] < 0) {
    writeUs(j, target);  // unknown start: one jump. Support the arm.
  } else {
    while (currentUs[j] != target) {
      int step = constrain(target - currentUs[j], -NUDGE_US, NUDGE_US);
      writeUs(j, currentUs[j] + step);
      delay(25);
    }
  }
  report(j);
}

bool pcaPresent() {
  Wire.beginTransmission(PCA_ADDR);
  return Wire.endTransmission() == 0;
}

void setup() {
  Serial.begin(115200);
  Wire.begin();
  delay(200);

  if (!pcaPresent()) {
    Serial.println(F("PCA9685 NOT found at 0x40. Check VCC, GND, SDA->A4, SCL->A5."));
    while (true) {}
  }

  writeReg(0x00, 0x10);  // MODE1: sleep so the prescaler can be set
  writeReg(0xFE, 121);   // PRESCALE: ~50 Hz with the nominal 25 MHz oscillator
  writeReg(0x00, 0x20);  // MODE1: wake, register auto-increment
  delay(1);
  writeReg(0x00, 0xA0);  // MODE1: restart
  for (uint8_t j = 0; j < JOINTS; j++) jointOff(j);

  Serial.println(F("ARM TEST. b = base, s = shoulder, e = elbow, w = wrist."));
  Serial.println(F("Examples: e1500   s+   bo   o (all off)   ?"));
}

void loop() {
  if (!Serial.available()) return;
  String cmd = Serial.readStringUntil('\n');
  cmd.trim();
  if (cmd.length() == 0) return;

  if (cmd == "o") {
    for (uint8_t j = 0; j < JOINTS; j++) jointOff(j);
    Serial.println(F("ALL joints OFF."));
    return;
  }
  if (cmd == "?") {
    for (uint8_t j = 0; j < JOINTS; j++) report(j);
    return;
  }

  int8_t joint = -1;
  for (uint8_t j = 0; j < JOINTS; j++) if (cmd.charAt(0) == JOINT_KEY[j]) joint = j;
  String arg = cmd.substring(1);
  if (joint < 0 || arg.length() == 0) {
    Serial.println(F("Start with b, s, e or w. Examples: e1500  s+  bo  o  ?"));
    return;
  }

  if (arg == "o") {
    jointOff(joint);
    report(joint);
  } else if (arg == "+" || arg == "-") {
    if (currentUs[joint] < 0) {
      Serial.println(F("That joint is off. Send a pulse first, like e1500."));
    } else {
      moveTo(joint, currentUs[joint] + (arg == "+" ? NUDGE_US : -NUDGE_US));
    }
  } else if (isDigit(arg.charAt(0))) {
    moveTo(joint, arg.toInt());
  } else {
    Serial.println(F("Use a number, +, - or o after the joint letter."));
  }
}

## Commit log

2026-10-04 Scribbot build: base, shoulder, elbow and wrist stages
    OpenSCAD source, printable STLs, assembly guides, diagrams and Arduino test sketches for each build stage.
    [01_PRINT_ONCE_four_motor_posts.stl, 01_base.stl, 01_base_v1.stl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]
2026-10-09 Calibrate the arm and add the drawing program
    Joint offsets and gains from three measured poses. draw.ino does inverse kinematics on the Nano and draws squares, circles, stars and text. Elbow and wrist limits widened after a clearance check.
    [arm_test.ino, draw.ino]
2026-10-15 Add vision: camera stand and copy-a-drawing
    A webcam on a printed stand looks at a doodle on a sticky note; copy_drawing.py finds the note, traces the ink and streams the strokes to the arm. The drawing program gets gear-slack settings for the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
2026-10-15 Repo cleanup: binary STLs, remove duplicate folder, add design index
    All STLs converted from ASCII to binary (39 MB to 12 MB, same geometry). Remove PRINT-NEXT-MOTOR-MOUNT, whose parts duplicate design/, and an empty measurements template. Add .gitattributes, a design/README.md index, and fix two stale references.
